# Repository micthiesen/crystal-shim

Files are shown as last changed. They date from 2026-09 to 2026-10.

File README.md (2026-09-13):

# Crystal Shim

A water-level interlock for an OASE CrystalSkim 350. An active sensor outside the
aquarium glass reports to an ESP32-C6; a separate mains board filters and switches
the skimmer. The controller and mains board share an enclosure with physical separation.

It runs on configurable 15-minute schedules when the water level permits, with
bounded HomeKit overrides. Every run ends automatically. See [behavior](docs/controls.md).
Pushover alerts report confirmed water-level transitions in either direction.
An ESP-hosted local webpage implements settings and schedules. The sensor
targets a freshwater tank with 5 mm glass. Its slim board adheres below the rim
with thin mounting film and a left-exiting pigtail.

**Build approach:** one complete design and fabrication cycle for all three
final-use boards. Complete design reviews before fabrication, then calibrate and
commission the assembled unit. No separate prototype phase is planned.

**Status:** the compact three-board designs are prepared for owner routing.
See [current state](docs/STATE.md) for current checks and accepted handoff receipts.
The C6 application includes sensing, relay/watchdog control, retained state,
private Matter provisioning, local settings and verified-TLS Pushover delivery.
The present hardware includes fixed 12 V power, three future pump drivers and a
second sensor port under the [refill attachment contract](docs/design/refill-expansion.md).
Future refill/conditioning behavior is deferred. Routing, fabrication release and
physical calibration/commissioning remain separate work.

Start with [the overview](docs/overview.md) and [current state](docs/STATE.md).
The [decision register](docs/decisions.md) tracks open inputs and release gates.

- [Design dossier](docs/README.md)
- [Firmware and simulator](firmware/README.md)
- [PCB tooling and three board areas](pcb/README.md)
- [Bill of materials](bom/README.md)
- [Commissioning matrix](testing/README.md)
- [Build sequence](docs/build.md)

Use the pinned toolchains described in the firmware and PCB READMEs. Then:

```sh
cd pcb
bun install --frozen-lockfile
cd ..
sh scripts/check.sh
python3 .agents/skills/sync/sync-status.py
```

Based on `../stillair`: Rust host core + CLI + separate ESP32-C6 app, Bun/tscircuit
authoring, and KiCad downstream production tooling. Relevant skills and tools have
a reciprocal sync map; Stillair's board designs and fan behavior are not imported.

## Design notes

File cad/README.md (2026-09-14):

# Mechanical artifacts

The [stencil fixtures](stencil-fixtures/README.md) provide printable PETG trays
for the three ordered PCBs, with STEP/STL/3MF exports, nominal shims, parametric
CadQuery source and digital fit checks. Physical fit remains untested.

The current [shared-enclosure plan and CAD screen](shared-enclosure/README.md)
uses Hammond 1590ZGRP243 for the stacked mains and controller boards. It retains
the manufacturer PDF and STEP archive, reproducible CadQuery script, actual
collision/distance results, negative controls and a reloaded STEP export.
See [mechanical requirements](../docs/mechanical.md) for mounting and cable limits.

`controller-fit/` and `mains-fit/` are historical nominal fit evidence for the
superseded 1554V2GY enclosure and earlier PCB sizes. Their machining, carrier,
portal and mating assumptions must not be applied to the current boards.

No enclosure production machining drawing is released.
The sensor uses thin adhesive film directly against the glass; no clip is required.
Its board and pigtail interface are specified in the mechanical requirements.

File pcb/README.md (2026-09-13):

# PCB workspace

All three product boards have accepted native schematic/placement handoffs with
prepared pours, routing widths and native DRC rules. Controller and mains share
150 × 110 mm outlines and aligned mounts; the adhesive sensor is 18 × 64 mm.
Expected unrouted connections are controller 166, mains 31 and sensor 21.
[STATE](../docs/STATE.md) records current per-board receipts and the six exact
sensor inner-shield padstack exceptions. Routing, final checks and fabrication
exports follow; physical commissioning remains separate.

Design the three boards as one final-use set for a single fabrication cycle.
Complete part, interface, enclosure and source/layout reviews before release.
There is no separate sensor prototype or planned board respin. Sensor calibration
and actual-load verification use the final boards after assembly; they do not
block the complete design's fabrication release. See [build order](../docs/build.md).

| Board | Role | Requirements |
| --- | --- | --- |
| [sensor](sensor/README.md) | External active capacitance sensor stick | [Sensor](../docs/sensor.md) |
| [controller](controller/README.md) | Low-voltage ESP, relay and future pump drivers, two sensor ports and USB | [Electrical](../docs/electrical.md) |
| [mains](mains/README.md) | Protected power input, isolated supply and pump switching | [Electrical](../docs/electrical.md) |

Use the local [PCB skill](../.agents/skills/pcb/SKILL.md) for product authoring, then
[Konnect](../.agents/skills/konnect/SKILL.md) and
[fabrication](../.agents/skills/kicad-manufacture/SKILL.md) for downstream work.
Tscircuit owns schematic, specifications, and placement; KiCad owns routing
and declared manufacturing additions. Do not create a fabrication profile before
the corresponding board and order requirements exist.

## Tooling validation

Versions and Oxc conventions come from Stillair. TypeScript is pinned to 5.9.3.
The root `.bun-version` and `.node-version` record the verified CLI runtimes;
`tsci` uses Node even though Bun manages dependencies and scripts.
From this directory:

```bash
bun install --frozen-lockfile
bun run check
bun run typecheck
bun run check:smoke
bun run test
bun run test:handoff
```

`fixtures/tooling-smoke.circuit.tsx` is a TOOLING-only, arbitrary RC circuit. Its
parts, values, dimensions and nets are unrelated to Crystal Shim. It checks that
the installed TSX compiler, placement, netlist and multi-file KiCad schematic
export work. Fixture outputs go under ignored `dist/`; they are unrelated to the
adopted controller. `bun run dev:smoke` opens the local fixture viewer when needed.

The Python tests exercise generic handoff protections using self-contained
synthetic fixtures. Passing this gate proves tooling behavior, not electrical
safety, sensor performance, real KiCad handoff parity, ERC/DRC, or fabrication
readiness. Native handoff requires the local KiCad macOS bundle and separate
evidence for each actual board. See [tools](tools/README.md).

The pinned build currently emits missing schematic reference-designator styling
warnings for the fixture's built-in R1/C1 symbols. The exported KiCad sheet is
tested to contain both reference fields. These warnings remain visible; future
product schematics require the separate render and parity review gates.

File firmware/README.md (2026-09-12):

# Firmware

Rust, bare-metal ESP32-C6, following `../stillair`: `core/` contains the `no_std`
control contract, `drivers/` contains async device drivers, `cli/` runs the control
model on the host, `matter/` contains the actual SDK command and KV adapters,
`settings/` supplies the local HTTP service/UI, `pushover/` owns bounded RAM
events and HTTP delivery policy, and `roughtime/` verifies signed time replies offline. `app/` is a separate workspace
targeting `riscv32imac-unknown-none-elf`. Stable Rust is declared in
`rust-toolchain.toml`; setup was verified with Rust 1.97.1. Commit each workspace's lockfile.

The ESP image is **uncommissioned**. It binds the controller capture pin map,
acquires FDC1004 frames on a separate interrupt executor, runs a 20 ms relay-output
task, services a 1,500 ms system-reset watchdog only after that task completes, and
streams bounded USB diagnostics. Boot validates saved settings/calibration and repairs
retained safety state through a relay-off flash gate. Missing or invalid settings keep
the output off. The runtime coordinator evaluates schedules, persists configuration
and suppression, and accepts bounded physical USB administration. The Matter
command and shared KV adapters, Wi-Fi/BLE commissioning and private credential
provisioning are implemented. The private switch profile follows D-22; Apple Home
pairing and behavior have not been exercised. The authenticated
[settings service](../docs/design/settings.md) includes schedule, threshold and
response timing controls. The [Pushover worker](../docs/design/pushover.md) is
linked through the same network; physical calibration workflow remains work. The external coil
pull-down must establish off before application entry and during reset; a build
cannot verify that physical behavior.

The separate [FDC1004 driver](drivers/README.md) implements reset, identity/config
checks and complete sequential out-of-phase measurement frames, with host tests.
It is bound to the ESP's 100 kHz bus with finite transactions and power recovery.
The [calibration stage](../docs/design/calibration.md) applies measured tank data
without fabricated default thresholds. The [integration design](../docs/design/firmware-integration.md)
distinguishes implemented executor and storage adapters from remaining network
integration. The [runtime transaction contract](../docs/design/runtime-transactions.md)
defines configuration saves, command acknowledgements and the USB protocol.
The [Matter adapter contract](../docs/design/matter-integration.md) defines producer
ownership, cancellation, applied replies and the single shared SDK storage owner.
The [configuration](../docs/design/configuration.md),
[timezone](../docs/design/timezone.md) and [flash-storage](../docs/design/flash-storage.md)
records describe the bounded models and current evidence.

The app uses the same compatible esp-hal revision as Stillair,
`10e48dd74837bae4be663a7d1825d12875363727`, for HAL, panic/log output, bootloader,
and generated metadata. Its lockfile was seeded from Stillair's to retain the
same transitive versions. HomeKit through Stillair-style Matter over Wi-Fi is
selected; radio dependencies and the shared network adapter are linked.
Keep the esp-* dependency family on one compatible revision.

The [offline signed-time verifier](../docs/design/unattended-time.md) is a host
workspace member with a checked C6 `no_std` library build. It is not linked into
the app or accepted as UTC. Its public captures and synthetic test identity are
offline fixtures. Conservative interval scheduling is implemented and reviewed.
Interval TLS operation leases are implemented. Signed-source agreement, drift
policy and unattended runtime acquisition remain work.

## Control contract

Stop-low / automatic restart-after-refill is confirmed. `Supervisor` is the public
control entry point; the lower-level interlock is crate-private and cannot serve
as an unscheduled hardware entry point. The core uses injected monotonic milliseconds and
integer calibrated levels in `0..1000` thousandths of the selected sensing range.
These are calibrated fractions, not millimetres. The integer calibration stage
converts measured capacitance response into this domain.
No real stop/restart thresholds or maximum sample age are supplied by default.

- Boot starts off. Automatic restart requires valid readings at or above the configured
  restart threshold, ten seconds of stable recovery, and thirty seconds off.
- During automatic operation, a level at or below the lower stop threshold must persist for
  one second before off. Readings above that threshold reset low confirmation.
- Disconnected, uncalibrated, out-of-range, bus-failed, stale, or future-dated
  readings cause immediate off. A backwards clock or a control-loop gap longer
  than the configured sample-age deadline also forces off.
- Recovery resets on faults and readings below the restart threshold. Cached
  readings retain their acquisition timestamp and cannot establish a recovery
  interval by themselves. The caller must tick periodically even without data.
- A manual override can bypass low-level and recovery gates for a valid, fresh
  sensor. It cannot bypass faults, maintenance, hardware-forced-off, or minimum
  off time. Faults, maintenance, and hardware-forced-off cancel an override rather
  than queueing it for later. A scheduled request can recover inside its original
  remaining window.
- Maintenance stays off until an explicit exit command. The runtime persists
  maintenance and window suppression through the gated storage owner, and exits
  maintenance only after its clear record is durable. Exit then requires fresh
  stable recovery. Final-board power-cut behavior still requires measurement.
- Network state is absent from the control contract, so future network tasks
  must not be able to prevent local sampling/control ticks.

The 1 s / 10 s / 30 s values are proposed tuning values from the design brief,
not validated OASE requirements. The maximum sample age also serves as the
allowed control-loop gap in this baseline. Set it from the selected acquisition
cadence and measured failure response. `RelayCommand` describes the requested
coil state; it provides no contact feedback or protection from welded contacts.

## Scheduled operation and HomeKit

`Inputs` carries a reading, optional `ScheduledWindow`, `SwitchCommand`,
maintenance command, and `HardwarePermit`. The runtime calendar adapter supplies
only active windows with a stable, strictly increasing `WindowId` and the
original absolute monotonic `ends_at`. It must preserve identities across
repeated ticks and schedule edits. `schedule.rs` implements bounded daily entries,
injected timezone resolution and stable occurrence IDs. `retained.rs` implements
the versioned safety record and boot recovery policy. The core timezone resolver
accepts explicit POSIX rules. The app loads saved settings, repairs retained state
at boot and stores eligibility before exposing a scheduled window. USB can supply
an explicit UTC observation; it ages automatically and expires after one hour.
The [trusted UTC path](../docs/design/trusted-utc.md) can also read an
administrator-configured Matter CASE source. A usable Home hub source has not
been demonstrated; unattended time availability remains open. No hours are guessed.
The intended starting schedule is fifteen minutes a few times per day.

Every run has an absolute deadline. The initial configurable maximum duration is
`900000` ms; the scheduler's window end may make an automatic run shorter. Low
water, recovery waits, and interruptions consume the available window. Recovery
never grants time beyond that end. A replacement or overlapping window cannot
extend an active run's original deadline. At expiry the supervisor forces off;
a later distinct window remains eligible after minimum-off and fresh recovery.

HomeKit exposes an advisory switch plus a temporary override:

- Off cancels any override, immediately requests off, and suppresses the remainder
  of the current scheduled window. A later distinct window is eligible again.
- On outside a window, or when automatic operation is stopped at valid LOW,
  requests an override for the configured maximum duration. Its deadline starts
  at the **request timestamp**. Minimum-off waiting consumes part of that allowance.
- Repeated On while an override is pending/running retains its original deadline.
  On during an energized automatic run may select override mode but retains that
  run's original deadline. It does not grant a fresh fifteen minutes.
- An On arriving on the expiry tick cannot renew the active run. A subsequent
  explicit On is a new request and still observes minimum off. Off followed by
  a new explicit On is also allowed.
- An override expires to off. It does not fall back into automatic operation in
  the current window. Neither HomeKit nor a schedule can command indefinite on.

All thresholds and timers are explicit configuration. The CLI supports them at
startup; `Supervisor::reconfigure` clamps an active deadline when duration decreases
and never extends it when duration increases. The runtime's configuration-save
transaction deliberately enters maintenance, preserves deadline history and
requires an explicit durable exit. The implemented [settings webpage](../docs/design/settings.md)
shows this consequence and keeps maintenance exit separate. Use the private
[first-configuration workflow](../docs/design/first-configuration.md) before Matter
commissioning. No final Matter node has been physically commissioned yet.
The generated async Matter handler reports the observed relay command and waits
for control-applied replies. Source-owned tokens prevent stale replies or another
producer from consuming them. Toggle resolves inside control. The linked radio
adapter preserves this boundary and runs the attribute notification handler;
final hardware behavior remains unverified.

## Water notifications

`SupervisorStatus.water_transition` emits one confirmed HIGH-to-LOW or LOW-to-HIGH
edge for the normal-priority Pushover adapter. Detection is independent of
relay command, schedule, manual override, and hardware permission. It uses the
same stop/restart thresholds and low/recovery confirmation delays. Initial valid
classification establishes a silent baseline. Intermediate-band readings and
invalid/stale data reset pending confirmation without inventing a water change.
Cached samples cannot prove a transition. `status()` does not replay an event.

Changing interlock configuration resets pending level confirmation and the notification baseline so calibration
or threshold edits do not masquerade as water movement. The [worker](../docs/design/pushover.md)
captures the fresh step after GPIO output, retains at most eight RAM events for
15 minutes, and uses one original 20-second TLS/HTTP deadline per attempt. It
checks the accepted clock authority, network and configuration token around
every I/O poll. There are at most three attempts; uncertain failures may duplicate
a message. Accepted settings replacement cancels old work before flash; failure
keeps delivery paused until a later save commits. HTTP 4xx or a complete API rejection suspends the credential generation
until it is changed or explicitly disabled and restored. Reboot clears queued
work and suspension. No live notification was sent.

## Verify

Run from the repository root. These are the same checks as
`.github/workflows/firmware.yml`:

```bash
sh scripts/check-tls.sh
cd firmware
cargo fmt --check
cargo clippy --locked --all-targets -- -D warnings
cargo test --locked
cd app
cargo fmt --check
sh ../../scripts/with-esp-toolchain.sh cargo clippy --locked --all-targets -- -D warnings
sh ../../scripts/with-esp-toolchain.sh cargo build --locked --release
cd ../..
python3 scripts/check_matter_features.py
```

Use `cargo fmt` in the appropriate workspace to apply formatting. The host tests
exercise meaningful control and parser behavior; the target build only proves
that the local-runtime image links. The separate TLS construction probe and host endpoint
checks are recorded in the provider document. Clang with a RISC-V backend is
required for its portable C dependency; on macOS the wrapper finds installed
Homebrew LLVM. No hardware or mains testing is implied.

The TLS policy harness compiles the production provider source directly and runs
offline certificate and clock tests on Linux. `scripts/check-tls.sh` uses native
Linux or the default OrbStack Linux machine on macOS. That environment needs Rust,
Clang, libclang and CMake. The script also checks production/test dependency and
crypto-feature parity; it does not silently skip TLS tests on an unsupported host.

## Host simulator

From `firmware/`, run `cargo run --locked -p crystal-shim-cli -- --help`. The CLI
accepts stop threshold, restart threshold, and maximum sample age, optionally
followed by low-confirmation, recovery, minimum-off, and maximum-run durations in
milliseconds. Omitted durations use the initial 1 s / 10 s / 30 s / 15 min seeds.
It reads one persistent simulation from stdin. Each event carries the injected
timestamp. It prints CSV control state, relay command, demand, deadline, water
classification and transitions, and exits
nonzero for malformed commands. Fault events are successful simulation inputs.

This short example uses **synthetic values**, not calibration recommendations:

```bash
printf '0 level 600\n0 window 1 900000\n100 disconnected\n200 maintenance-on\n300 level 600\n400 maintenance-off\n' |
  cargo run --locked -p crystal-shim-cli -- 200 400 500
```

Supported lines are `<ms> level <0..1000>`, `<ms> tick`, `<ms> disconnected`,
`<ms> uncalibrated`, `<ms> out-of-range`, `<ms> bus-fault`,
`<ms> maintenance-on`, `<ms> maintenance-off`, `<ms> window <id> <absolute-end-ms>`,
`<ms> no-window`, `<ms> on`, `<ms> off`, `<ms> hardware-off`, and
`<ms> hardware-on`. Blank lines and `#` comments
are ignored. `tick` reuses the last reading without renewing its timestamp.
Supply successful acquisitions frequently enough to meet the configured age
deadline. A single leap forward in time cannot simulate uninterrupted sampling.

Bind hardware drivers to reviewed GPIO/net assignments from the complete board
design. During commissioning of the final assembled boards, validate electrode
calibration on the confirmed glass/range, measured thresholds, maximum sample age
and cadence, watchdog behavior, maintenance/window-suppression persistence,
calendar scheduling, Matter/Pushover adapters, and diagnostic storage/transport
for raw capacitances, interpreted level, validity, relay command and reset reason.
Physical calibration follows fabrication; it does not block implementing the
hardware bindings.

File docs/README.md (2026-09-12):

# Design dossier

The 2026-09-11 setup request is the initial design brief. These documents retain
its architecture, provisional choices, caveats, and acceptance goals. Verified
manufacturer facts are linked separately from proposed design decisions.

The owner selected a one-shot build: develop and review the complete three-board
design, fabricate one final-use set, then calibrate and commission it. The
[build sequence](build.md) separates design evidence required before fabrication
from measurements performed on the final assembly.

| Document | Owns |
| --- | --- |
| [Overview](overview.md) | Purpose, scope, board split, functional diagram |
| [Electrical](electrical.md) | Power, mains switching, noise suppression, interfaces |
| [Sensor](sensor.md) | Electrodes, daughterboard, calibration, glass validation |
| [Controls](controls.md) | Local firmware contract, diagnostics, provisional timing |
| [Mechanical](mechanical.md) | Enclosure separation, installation, assembly |
| [Decisions](decisions.md) | Baseline, open inputs, release gates |
| [Build](build.md) | Development and commissioning order |
| [Sources](sources.md) | Manufacturer references and Stillair evidence |
| [Detailed design](design/README.md) | Parts, geometry, interfaces, calculations and firmware integration under review |
| [Active goal](goal.md) | Full implementation, adversarial review and delivery scope |
| [STATE](STATE.md) | Current work and next step, with pointers to durable facts |

`Proposed` means a starting choice; `open` means unspecified; `verified` requires
linked evidence. A component rating does not establish whole-product compliance.
Update the owning document, BOM, and test matrix together when a choice is resolved.
`Capture candidate` identifies an exact proposed part with source evidence; it
does not mean the layout has passed release review or that procurement is ready.

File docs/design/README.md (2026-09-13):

# Detailed design basis

These documents turn the requirements into concrete engineering selections for
schematic and firmware implementation. They are candidates under review, not fabrication
release or commissioning evidence. Their explicit open items remain work to finish.

- [Sensor](sensor-design-basis.md): TI OoP topology, glass/rim geometry, references,
  local regulation, I2C, adhesive interface and retained visual reference.
- [Sensor-cable protection](sensor-cable-protection.md): exact ESD selections,
  bus loading and final-system immunity limits.
- [Sensor power refinement](sensor-power-refinement.md): RC protection, PGFB diode,
  voltage/load/capacitance budgets and finite backfeed calculations.
- [Controller](controller-design-basis.md): module pins, power and service inputs,
  USB attach gating, relay driver, power-good interlock and harnesses.
- [Controller service pads](controller-test-points.md): exposed supply, bus, relay
  and UART points, probe access, mask and no-paste export rules.
- [Mains and enclosure](mains-design-basis.md): PSU, relay, filter, fuse/MOV/RC,
  mains harness, PE, spacing and enclosure allocation.
- [Secondary power protection](power-protection-review.md): selected 2 A supply,
  reverse-blocking eFuse networks, static margins and remaining transient review.
- [Firmware integration](firmware-integration.md): schedule/retained state,
  executor ownership, Matter, HTTP, Pushover, storage, USB and resource gates.
- [Calibration](calibration.md): measured TI response normalization, integer arithmetic,
  raw envelopes, frame ordering and validity checks.
- [Configuration](configuration.md): validated settings and canonical bounded storage format.
- [First configuration](first-configuration.md): private initial record creation,
  offline validation and one-shot USB delivery before Matter commissioning.
- [Local settings](settings.md): actual HTTP service, browser UI and durable command admission.
- [TLS restriction](tls-restriction.md): borrowed rejection-only certificate callback,
  interval operation lease and vendor provenance.
- [Pushover delivery](pushover.md): fresh water events, bounded RAM queue, verified
  HTTP worker, cancellation and failure diagnostics.
- [Controller grid](controller-grid.md): initial coordinate conversion and verified native-save connectivity.
- [Timezone](timezone.md): explicit POSIX rules, DST folds/gaps and calendar limits.
- [Flash storage](flash-storage.md): output-off ownership, bounded flash chunks and boot recovery.
- [Runtime transactions](runtime-transactions.md): durable settings, schedule eligibility,
  immediate Off, sensor revisions and bounded USB administration.
- [Matter adapter](matter-integration.md): generated command handling, producer ownership,
  applied reporting, shared gated KV and the remaining radio/profile integration.
- [Verified TLS](tls-provider.md): fixed Pushover trust policy, C6 build,
  live endpoint checks, measured linked size and remaining runtime evidence.
- [Footprint audit](footprint-audit.md): installed-library candidates, manufacturer
  comparisons and exact patterns still required before capture release.
- [Manufacturing output profile](manufacturing-output.md): three-board assembly split, order construction, export path and final checks.
- [Review record](review-log.md): findings, corrections, rejected claims and
  scopes that still require review.

The [active project goal](../goal.md) covers implementation, repeated adversarial
review, manufacturing output and final-unit commissioning support. No board is
released by a document's use of an exact part number or dimension.

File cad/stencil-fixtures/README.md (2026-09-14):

# PCB stencil fixtures

Three square PETG trays for the ordered bare PCBs, with a flat stencil/tape
surface, oversized pocket, three locating pads and three flexible edge tabs.
Source uses **CadQuery 2.8 + uv**, the same approach as `../cat-water-cover`.
All dimensions are millimetres. STEP, STL and geometry-only 3MF exports are
already oriented flat on the bed, pocket upward, at Z=0.

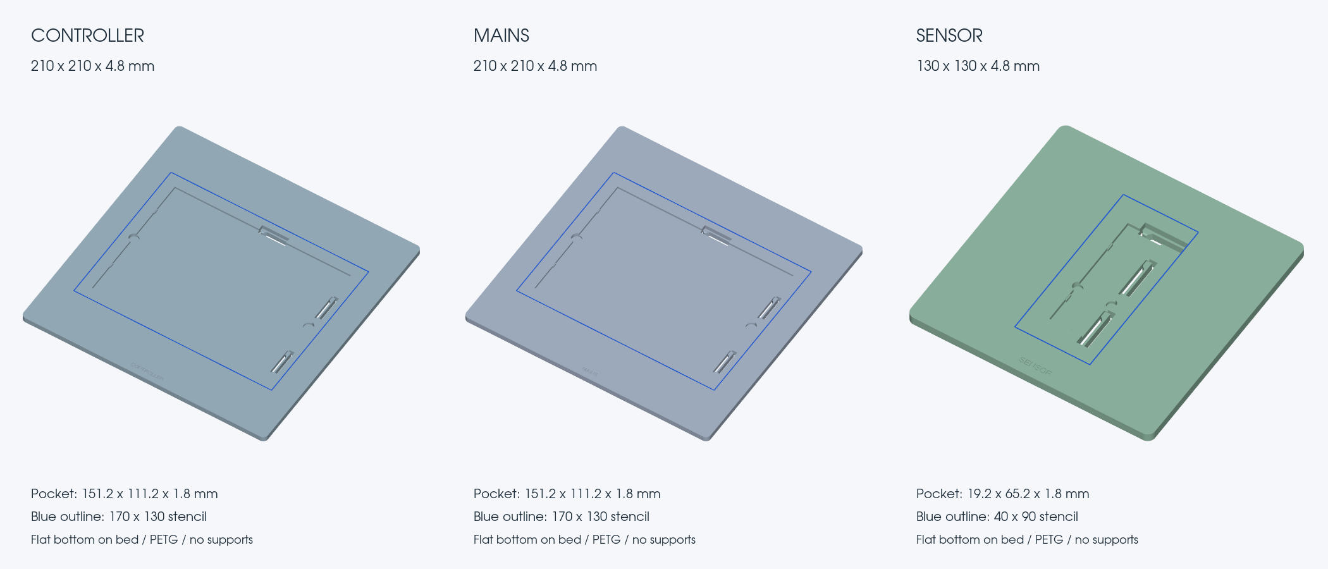
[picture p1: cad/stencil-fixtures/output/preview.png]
Rendered STEP trays; blue outlines show the custom stencil sizes


## Print files

| PCB | Tray STEP | Outer size | Pocket, before locating features | Ordered custom stencil |
| --- | --- | --- | --- | --- |
| Controller | [controller-tray.step](output/controller-tray.step) | 210 × 210 × 4.8 | 151.2 × 111.2 × 1.8 | 170 × 130 |
| Mains | [mains-tray.step](output/mains-tray.step) | 210 × 210 × 4.8 | 151.2 × 111.2 × 1.8 | 170 × 130 |
| Sensor | [sensor-tray.step](output/sensor-tray.step) | 130 × 130 × 4.8 | 19.2 × 65.2 × 1.8 | 40 × 90 |

Each has matching `.stl` and `.3mf` files in `output/`. The two large trays have
the same fit geometry and different recessed names. One large tray can serve
both PCBs if doing them in sequence. There are also three separately exported
`*-shim-0.2mm.step`, `.stl` and `.3mf` sheets for nominal height adjustment.
The shims are optional print files: measured thin sheet material works too.

The centred stencil has 20 mm minimum border beyond its edges: 20/40 mm in
X/Y for the large trays, 45/20 mm for the sensor. The tray does not locate or
recess the stencil. Align its apertures visually to the pads and tape onto the
flat border. The blue lines are preview annotations, not printed grooves.
The purchase listing's 380 × 280 mm stock size is recorded separately from its
custom cut sizes in the [order record](../../bom/purchases/W2026091502305469/README.md).
Actual aperture centring within each supplied sheet is unmeasured.

## Material and slicer settings

**Use ordinary PETG**, with a 0.4 mm nozzle. The broad tray should stay firm
under a squeegee; flexibility is concentrated in the thin tabs. PETG has useful
toughness and some flexibility ([Prusa material guide](https://help.prusa3d.com/article/petg_2059)).
TPU would make the entire support more compliant and is not the selected
material. PLA may work, but the spring design has not been checked with PLA.

- Print one tray flat, pocket up, at **100% scale**. No supports or raft.
- Use **0.20 mm layers**, including the first layer, **4 walls**, **5 top and
  5 bottom layers**, and about **25% gyroid infill**. Select your filament's
  normal PETG temperature/flow profile.
- The 1.2 mm beams are three nominal nozzle widths. Inspect the sliced preview
  to ensure continuous walls in each beam and clear slots. Keep automatic
  supports off and prevent brims from filling the internal spring slots.
- Use a clean, flat build plate. Use an external brim only if your PETG profile
  needs it; remove it fully. Keep the tray on a hard, flat bench during pasting.
- Remove strings and any raised top-surface defects. Do not round the seating
  plane or datum pads. Check the tray does not rock and the pocket floor is flat.
- Print a nominal shim separately as **one 0.20 mm layer**, 100% solid, no brim
  or ironing. Its actual thickness still needs checking; a calibrated sheet is
  preferable if first-layer variation makes the printed shim uneven.

The 210 mm tray fits the smaller 235.5 × 256 mm nozzle envelope used by the
cat-water-cover project. No printer preset or sliced toolpath is embedded in
these exports. This is an ambient-temperature paste fixture; lift the PCB out
before hot-bed/reflow work.

## Flush height and use

All three PCB orders specify **1.6 mm nominal thickness**. JLCPCB publishes
1.44–1.76 mm for this thickness ([capabilities](https://jlcpcb.com/capabilities/pcb-capabilities)).
The **1.8 mm pocket** allows a shim under even a thicker board. A nominal
1.6 mm board plus a **0.2 mm shim** brings its top to the 4.8 mm tray surface.
The stencil foil sits on top of both surfaces; its thickness is not added to
the pocket depth.

1. Clean the bare PCB and tray. Before any paste, measure the PCB thickness
   and the actual printed pocket depth.
2. Select a broad, flat shim: **shim thickness = pocket depth − PCB thickness**.
   For the nominal model, the published board tolerance needs 0.04–0.36 mm.
   Use measured polyester/Kapton sheet or evenly stacked thin paper if the
   supplied 0.2 mm print is not right. Cover the support floor broadly; avoid
   small stacks at isolated points that let the board bend under the squeegee.
3. Set the shim on the floor, clear of the spring slots. Lower the PCB against
   the left and bottom datum pads. Gently pull the right/top tabs outward as
   needed; their bevels assist insertion. They press on the edges, with no lip
   over the board. Do not force a board through a tight or fused slot.
4. Lay a straightedge across the tray and PCB in several directions. Adjust
   until they are coplanar, without a visible step or a gap beneath the stencil
   at the paste openings. Target within approximately 0.05 mm; the printed shim
   alone does not establish this. If the bare PCB stands proud without any shim,
   deepen/regenerate the pocket rather than force the stencil flat.
5. Visually align the stencil and tape a hinge along one edge. Tape the opposite
   edge after checking alignment. Place tape outside the PCB/paste field and
   away from the moving tabs. Confirm the PCB cannot shift in a dry pass.
6. Squeegee toward the fixed left/bottom pads so the stroke pushes the PCB into
   its stops. Lift the stencil on the tape hinge, then lift the PCB through
   the two small edge wells with a plastic pick while easing the tabs back.
   The wells expose an underside edge without making large holes under the PCB.

Paste all three boards **before through-hole parts or the sensor pigtail**.
These fixtures are for the single top-side bare-board pass in the
[assembly guide](../../docs/assembly/README.md).

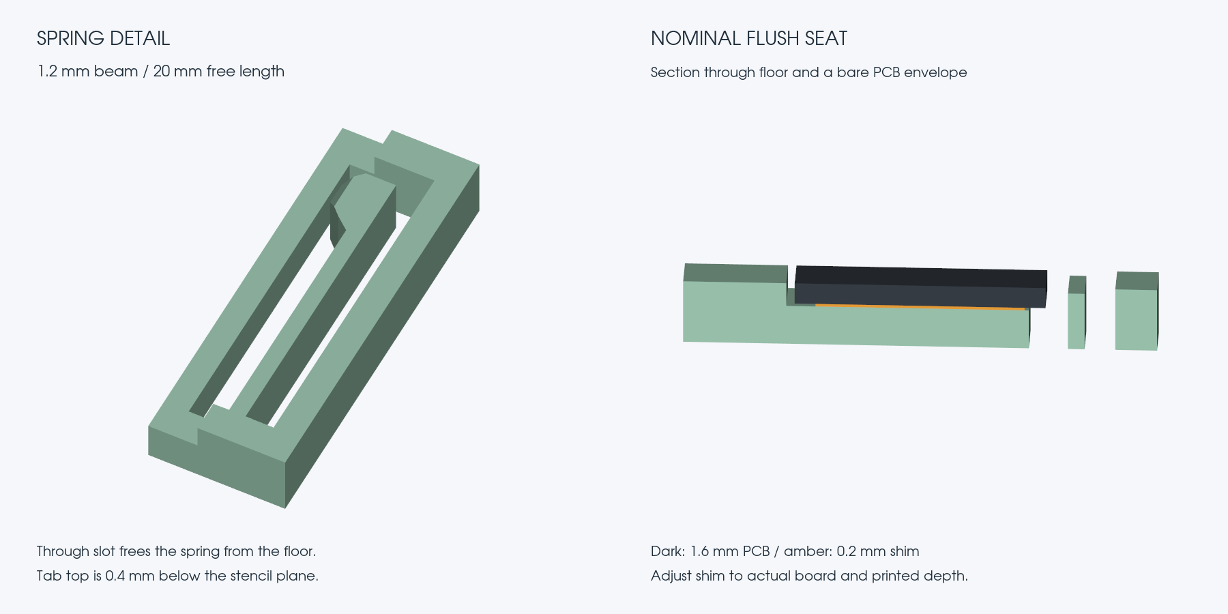
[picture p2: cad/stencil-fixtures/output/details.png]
Spring detail and section through the nominal flush PCB and shim


## Fit features

- Pocket clearance is 0.6 mm per side, with square inside corners to accommodate
  the released sharp rectangular board outlines and unspecified sensor deburring.
- Two left pads and one bottom pad establish position. Two right springs and
  one top spring press the board against those pads.
- Each spring has a 1.2 mm beam, approximately 20 mm free length, 0.6 mm nominal
  preload and 1.2 mm checked lateral free travel. The ordered ±0.2 mm outline
  tolerance requires 0.4–0.8 mm nominal deflection. Remaining travel provides
  adjustment margin, not a guarantee of printer accuracy or holding force.
- Slots extend through the tray, so the floor does not lock the springs in
  place. Everything grows upward from the bed without a suspended underside.
- Tabs and datum pads finish 0.4 mm below the stencil-support plane. Text is
  recessed. There are no locating pins through stencil holes or PCB mounts.
- The 3 mm floor and broad shim support the bare PCB during squeegee pressure.

## Rebuild and review

```sh
cd cad/stencil-fixtures
uv sync --locked
uv run python build.py
uv run python validate.py
uv run python render.py
```

`build.py` owns all dimensions. If revising `DEPTH` for a measured board, retain
layer-compatible heights and review `SHIM`, the nominal shim filenames, the
validator's thickness/shim limits and the section preview together. Rerun all
three commands after a geometry change.
`output/parameters.json` binds dimensions to the order and released outline
Gerber hashes. `output/validation.json` binds the exported print geometry to its
source and dependency lock. [review.json](output/review.json) records this
release's independent and visual review; changed source/exports invalidate its
hashes and need another review.

The validator reloads STEP files, checks single valid solids and watertight
STL/3MF meshes, compares nominal source/export geometry, checks all 27 combinations
of board length/width/thickness per tray, checks spring clearance and intentional
preload, rejects an oversize-board negative control, checks shim clearance and
removal, and checks that consecutive 0.2 mm layer sections need no overhang
support. Spring displacement checks translate the free beam envelope; they are
not finite-element analysis. The simple maximum beam-strain estimate is 0.54%,
without a material strength or fatigue claim.

The previews render the exported STEP solids. PCB blanks and blue stencil
outlines are labelled nominal envelopes. Physical fit, retention force, print
flatness and paste results remain untested until the boards arrive. The
supplier-selected stencil foil thickness also remains unconfirmed; the earlier
0.10 mm paste review is a design basis, not evidence of the delivered foil.

**2026-09-14 review:** all six STEP/STL/3MF parts passed, with 81 PCB tolerance
cases across the three trays. Independent review found and closed a sensor
access-well/spring conflict; final renders were inspected. `sh scripts/check.sh`
passed, with its 43 conditional native integration checks skipped by the normal
harness. No native PCB file changed, and no electrical review or physical test
is claimed by this fixture work.

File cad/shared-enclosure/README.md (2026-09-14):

# Shared enclosure fit

The retained **Hammond 1590ZGRP243** accommodates the matching **150 × 110 mm**
boards as a stack, controller above mains, with **45 mm clear board-face spacing**.
The separate mains filter remains beside the stack. This screen uses actual
manufacturer enclosure solids and declared rectangular assembly/access reserves;
it does not establish exact component, cable, insulation or thermal acceptance.

- [Fit results](fit-results.json): dimensions, clearances, sensitivity and negative controls.
- [CAD screen](fit-screen.step): enclosure and current stacked reserve solids.
- [Manufacturer drawing](source/1590ZGRP243.pdf) and original STEP ZIP are retained.
- [Reproduction script](check_fit.py): requires CadQuery; run
  `python cad/shared-enclosure/check_fit.py`.
- [Old side-by-side plan](fit-plan.svg): historical, superseded by this stack.

Both board outlines occupy X100..250, Y65..175 mm in enclosure-floor coordinates.
Mains PCB bottom/top are Z15/16.6; controller bottom/top are Z61.6/63.2.
Four aligned mounting columns have centres **(107,72), (243,72), (107,168),
(243,168)**. Use insulating M3 hardware within the 8 mm maximum reserved diameter.
The selected support construction below fixes spacer, washer and carrier geometry;
board-load and fastening performance remain physical checks.

An **intact 158 × 118 × 2 mm insulating separator** occupies X96..254,
Y61..179, Z50.1..52.1. Its lower face is 3 mm above the allocated 30.5 mm supply
height; it leaves 6.5 mm to the upper assembly's underside reserve at Z58.6.
The support construction below selects FR-4 and edge retention without separator
penetrations. Wire routing and as-built electrical insulation still need inspection.
No RF notch is selected.

Allow **35 mm outward mating/wiring depth** at each used edge. Lower primary
fixed terminals exit left and south; lower isolated headers exit right. Upper sensor
headers exit north, service connectors south and pump outputs right. The north
reserve stays left of the antenna. These are space allocations, not measured
housing withdrawal distances, cable bend radii or exact crimp models. Mains
J1–J4 now use 21.5 mm-high Phoenix Contact 1868076 terminals, within the existing
30.5 mm lower assembly height reserve. Their top screws require removal of the
controller and separator with mains disconnected. The gross reserve geometry
is unchanged; the historical fit receipt is not an exact terminal assembly model.

The filter/wiring reserve is rotated to **75 × 130 × 40 mm**, at X292..367,
Y40..170, Z10..50. Its nominal enclosure clearance is **5.40 mm**; expanding the
reserve by 1 mm and lowering the lid/hardware 1 mm leaves **4.00 mm**. Keep LINE
and LOAD wiring separate. This reserve contains the retained external filter and
its cable allowance, not an added component or a final mounting drawing.

The module's actual antenna envelope remains beyond the upper board's north
edge. Its minimum distance to the lower assembly reserve is **16.1 mm**. The
screen checks at least 15 mm to the enclosure, lower components, filter and
external harness reserves. The intact dielectric separator is tracked separately;
its influence on RF performance remains unmeasured. The board's local copper
exclusion and module support rules remain authoritative.

The optional manufacturer steel inner panel is excluded. Base, lid, screws and
gasket remain in every enclosure test. All nominal reserve volumes and the 1 mm
expanded reserves clear the enclosure, including a lid lowered 1 mm to account
for the STEP/drawing height discrepancy. Independent reserves do not intersect;
intentional mating interfaces may touch. Three negative controls detect wall,
lid and lowered-separator collisions. The exported STEP reloads as **19 valid
solids**. No route, fabrication, machining or assembled ingress rating follows
from this gross-fit result.

## Selected insulating support assembly

[Support construction](../../docs/design/evidence/pre-fab-2026-09-14/mechanical-closure.md)
now specifies a stock FR-4 carrier, two upper rails, four external nylon rods and
corner clamps that preserve the hole-free separator. The PCB elevations and hole
pattern above remain unchanged. [Support CAD](support-fit.step) and
[results](support-fit.json) are reproduced with `python check_supports.py` from
this directory, using the same CadQuery environment as the original fit screen.

The precise manufacturer-solid check locates the inner base surface at **Z1.8**
and outer base surface at **Z−4.0** at all six chosen base fastenings. Earlier text
called the retained Z0 datum the floor; it is a reference datum, not that local
surface. Carrier feet therefore have **3.2 mm** effective height to carrier Z5.
The new geometry checks actual base material, support/harness interference and
negative controls. Exact fastener engagement, physical loads, sealing, PE continuity
and the dielectric supports' RF effects remain assembly/commissioning checks.

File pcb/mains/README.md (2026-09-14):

# Mains board

The 22-part shared-power source and 150 × 110 mm placement allocation live in
[design](design/README.md). The IRM-45-12 supplies a separately fused 12 V motor
feed and AP63205-regulated 5 V controller/relay rail. The original skimmer filter
and relay behavior remain. F3 is the board-mounted T1A filter branch fuse; F2 is
the 3 A motor-feed fuse. F1 inlet fuse, manufactured filter and continuous PE
wiring remain offboard.

See the [design basis](../../docs/design/mains-design-basis.md),
[placement](../../docs/design/mains-placement.md), and
[native handoff](../../docs/design/mains-native-handoff.md). The [native project](kicad/README.md) has the accepted stacked placement,
right-angle connectors, filled isolated pours and installed routing rules.
Routing is accepted with zero unconnected items and clean strict ERC/parity/DRC.
See [routing acceptance](../../docs/design/evidence/mains-routing-acceptance/README.md).
Combined three-board pre-fabrication review remains pending.

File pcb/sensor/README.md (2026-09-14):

# Tank sensor daughterboard

The [authoritative source](design/README.md) captures and places the final-use
FDC1004 board for 5 mm freshwater aquarium glass and a 50 mm physical span below
the rim. Optional live dry RE is omitted in favour of stored dry baselines.
A future reservoir sensor may reuse the electrical interface, but its electrode
geometry is outside the present feature scope.

The accepted [native project](kicad/README.md) is 18 × 64 mm with four layers,
horizontal glass-side electrodes, inner driven shields and a left-exiting soldered
pigtail. Owner routing is complete with zero unconnected items; the exact routing is
accepted separately from the final three-board pre-fabrication review. See [STATE](../../docs/STATE.md) for validation and the
exact intentional inner-shield padstack exceptions.

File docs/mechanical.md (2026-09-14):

# Enclosure, mounting and assembly

## Shared controller and mains stack

Use matching **150 × 110 mm** boards, with the four-layer controller above the
two-layer mains/power board. Both are nominal 1.6 mm FR4 with components upward.
This is the accepted compact layout: the mains board shrinks from 180 mm wide,
while the controller grows from 110 mm to share its outline. The stacked bare
PCB footprint is 16,500 mm², approximately 48% below the former combined board
area. Connectors, cables, antenna, external filter and enclosure add space.

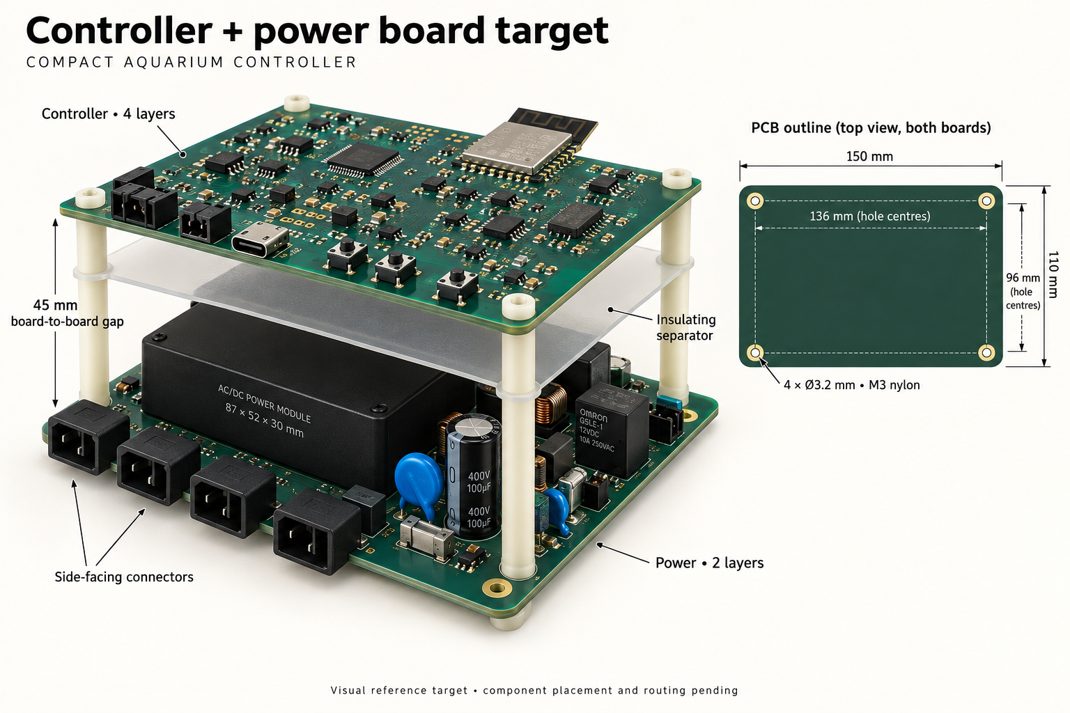
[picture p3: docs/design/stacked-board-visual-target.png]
Accepted stacked-board appearance


The generated visual reference is illustrative. Component appearances, connector
counts and relay markings do not change the BOM. The selected 5 V relay and
power architecture remain authoritative; no extra rendered capacitors or parts
are added. Source placement and native checks govern exact geometry.

| Mounting feature | Requirement |
| --- | --- |
| Holes on both boards | Four aligned 3.2 mm NPTH holes |
| Centres from upper-left, X right/Y down | (7,7), (143,7), (7,103), (143,103) mm |
| Source-centred coordinates | X=±68 mm, Y=±48 mm |
| Centre spacing | 136 × 96 mm |
| Hardware | M3 insulating screws, washers and standoffs |
| Hardware reservation | At least 4 mm radius per hole, no component/copper occupancy |
| Clear separation | 45 mm from lower PCB top face to upper PCB underside |

Match effective spacer length after washers and separator supports. Reserve
approximately 75–80 mm overall assembly height including floor standoffs and
upper access, subject to final enclosure geometry. Support the 195 g supply
without excessive board flex. Keep exactly four aligned mounting columns.

The retained IRM-45-12 sets the minimum practical stack volume: 87 × 52 mm nominal
body, 88 × 53 mm source allocation and 30.5 mm maximum allocated height. The
45 mm gap leaves 14.5 mm before upper underside projections, separator and
tolerances. The MOV has a 29 × 29 mm courtyard and 26.5 mm height reserve; the
relay has a 29 × 12.7 mm envelope and 15.7 mm height. These allocations explain
the common board size; they do not establish thermal or physical assembly tests.

Use **Phoenix Contact 1868076 (MKDS 5/2-7,62)** fixed side-entry screw
terminals on lower-board J1–J4. Each uses both positions. Their bodies are
15.24 × 12.5 × 21.5 mm, below the existing 30.5 mm supply height allocation.
Reserve 35 mm outward wiring access; top screw access requires removing the
controller and separator with mains disconnected. Lower J5/J6 retain right-angle
Micro-Fit mating, latch release and withdrawal paths outward from accessible
edges. Controller service J2 is JST S2B-XH-A, physically distinct from the
12 V Micro-Fit ports. Separate filter LINE/LOAD wiring. Controller buttons,
USB and test points remain accessible from above or an edge.

Preserve the controller antenna overhang and 15 mm three-dimensional reserve
from lower components, copper, wiring, conductive hardware and enclosure walls.
The intact dielectric separator has a separately recorded 11.1 mm antenna gap;
its RF influence remains unmeasured. Keep the inner controller
ground reference and USB geometry in [the stack contract](design/controller-stackup.md).
Retain an insulating separator between mains and controller with mechanically
secured supports and edges. Check primary wires, solder tails and unused metal
as well as board copper against the existing 8 mm primary-to-SELV and 3.2 mm
different-primary-net requirements. Spacer length alone is not insulation
acceptance. Keep ventilation and final-unit temperature checks for the stack.

## Selected support construction

Use the [stock-material mounting construction](design/evidence/pre-fab-2026-09-14/mechanical-closure.md)
and its [manufacturer-solid CAD check](../cad/shared-enclosure/support-fit.json).
A 182 × 144 × 3 mm insulating FR-4 carrier supports the lower board on plain
7 mm spacers. Two FR-4 upper rails on four external M4 nylon rods support the
controller on plain 3 mm spacers, preserving its 45 mm clear separation. Eight
corner tabs and eight insulating edge-stop screws retain the separator without
holes or an RF notch. Use single through-bolts at PCB supports, not opposing
screws in short spacers. All PCB mounting hardware stays within the 8 mm reserves.

The four frame/base holes are at enclosure coordinates (90,55), (260,55),
(90,185), (260,185), with 4.4 mm bores. The actual base surface is Z1.8 at those
points; 3.2 mm effective feet place the carrier underside at Z5. The separate PE
bracket sits at X270..310,Y180..210,Z10..13, fastened at (275,195), (305,195).
Its central M4 PE junction uses an independently clamped metal ring stack and
an insulating cover. Base penetrations need sealing and as-built inspection.
The construction record gives stock sizes, fasteners and the complete cut pattern.

The new support/harness/enclosure interference check passes against the retained
manufacturer solid. No conductive support is added near the antenna; new dielectric
rails approach to 5.44 mm and their RF influence remains unmeasured. Mechanical
load, fastening, PE continuity, sealing and physical commissioning remain as-built
checks. The separator itself and PCB positions are unchanged.

## Enclosure and wiring

The retained enclosure candidate is **Hammond 1590ZGRP243**: 400 × 250 × 120 mm
nominal outside, 384.85 × 235.26 × 109.20 mm inside per drawing. Its unmodified
glass-reinforced polyester assembly is UL94 V-0/IP66; cutouts and glands require
their own suitable installation. [Manufacturer](https://www.hammfg.com/part/1590ZGRP243),
[retained drawing](../cad/shared-enclosure/source/1590ZGRP243.pdf).

The [current shared CAD screen](../cad/shared-enclosure/README.md) verifies the
stack against retained manufacturer enclosure solids. Matching boards occupy
X100..250, Y65..175 mm. Lower board top is Z16.6 mm and upper underside Z61.6 mm.
The intact 158 × 118 × 2 mm separator sits at Z50.1..52.1 mm, above the allocated
supply body. Outward connector/wiring reserves extend 35 mm. The separate filter
reserve clears the enclosure by 5.40 mm nominally and 4.00 mm with the recorded
fit allowance. These are occupied-volume checks, not measured thermal or RF
performance. Final supports, glands and cable construction use this stack;
former side-by-side evidence is superseded.

The manufactured filter remains beside the stack with separate dirty LINE and
clean LOAD routing, away from sensor wiring and the ESP antenna. Preserve its
terminal and wire-bend allocation; board size is not the complete mains assembly
footprint. Use insulating carriers rather than a common steel panel. Keep mains
terminations inaccessible, provide strain relief and drip management, use GFCI
protection, and retain continuous PE to the filter case, output and any conductive
parts requiring bonding. Disconnect mains before opening or servicing.

Place the enclosure on the available flat surface behind the tank with its sensor
connection within the **203.2 mm complete harness limit**, including internal
routing. No old enclosure rotation, gland coordinate or 60 mm internal allowance
is an accepted measurement for this stack. Final strain relief and cable geometry
must establish reach without pulling the sensor off the glass.

## Sensor adhesive interface

Use the **18 × 64 mm** four-layer sensor entirely below the rim on the outside of
5 mm freshwater aquarium glass. Top edge is 2 mm below the rim; water is at least
10 mm below it. The mask-covered B.Cu sensing face adheres to glass with thin,
uniform mounting tape or transfer film. No clip, rail, bracket or mounting plate
sits between PCB and glass. Avoid foam and trapped air; the owner selects tape
and its installed thickness becomes part of final calibration.

Electronics and six pigtail solder lands face outward. The cable exits left when
viewed from outside, with outward-side strain relief. Anchor its jacket to adjacent glass using two
nonconductive tie bases with VHB 5952 and a relaxed bend to J1, as specified in
the mounting construction. Keep foam tape under those external anchors only.
Preserve a flat glass-facing
surface without exposed solder, through-hole connector tails or mounting holes.
The [sensor specification](sensor.md) defines the 50 mm physical electrode span
and lower wet reference. The accepted image remains a visual reference, not a
claim of measured sensitivity, adhesive durability or usable travel.

Protect the board from splashes and cable loads. Measure gap/adhesive effects,
replacement repeatability and final calibration on the assembled unit. No owner
clip CAD is required. This project owns its board/adhesive/pigtail interface.

## Verification boundary

Use current source/native placement, planes, routing rules and rendered geometry
before routing. Final routed ERC/DRC and manufacturing checks remain mandatory;
actual temperature, skimmer interference, sensor calibration and mounting durability
remain commissioning tests. A source or CAD screen cannot pass those measurements.

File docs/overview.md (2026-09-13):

# System overview

Crystal Shim monitors aquarium water level through the outside glass and controls
an OASE CrystalSkim 350. It runs for a configurable 15 minutes a few times daily
when enough water is present. Automatic low-water stop/recovery and timed HomeKit
switch overrides are confirmed requirements. Every run ends automatically; an
explicit override can run at a valid low level. See [the control contract](controls.md).

The project targets one complete, final-use three-board build. There is no separate
sensor prototype or planned PCB revision cycle. Resolve geometry, interfaces and
component selection through reference research, calculations and design review
before fabrication; calibrate and verify actual performance on the final assembly.
See [the build sequence](build.md).

The present boards must reserve the [future refill expansion interface](design/refill-expansion.md)
before fabrication. Three future pump drivers and two sensor ports belong on the
controller; the mains board supplies fixed 12 V accessory power and regulated 5 V
base power. Only accessories and a reservoir sensor board are added later. The
refill/conditioning feature remains deferred; its specification stays in the linked
Executor artifact.

The North American skimmer is specified at 120 VAC, 60 Hz, 4 W. Starting behavior
must be accounted for in relay and fuse selection from documented ratings and
design margins, then measured during final-assembly commissioning.
[OASE product specifications](https://www.oase.com/en-US/aquarium/crystalskim-350).

## Three boards

| Board | Location | Responsibility |
| --- | --- | --- |
| Sensor daughterboard | Outside aquarium glass | Continuous level electrode, wet reference and stored dry baselines, FDC1004, local 3.3 V regulation |
| ESP controller | Low-voltage enclosure section | ESP32-C6, 3.3 V rail, USB programming, relay driver, three reserved pump drivers, two sensor ports, status LED, maintenance button |
| Mains board | Mains enclosure section | Protected input, isolated PSU, relay contacts and coil, pump output suppression |

The sensor is 18 × 64 mm with common-net horizontal sensing bars, thin adhesive
mounting entirely below the rim and a left-exiting pigtail. The controller and
mains boards share 150 × 110 mm outlines and aligned M3 mounts; the controller
sits above mains with 45 mm clear separation. See [mechanical design](mechanical.md)
for the retained visual references and exact interface requirements.

The manufactured two-stage EMI filter sits alongside the mains board. The PSU is
always powered when mains is present, regardless of relay state. Its secondary
and the relay coil occupy a defined low-voltage region on the mains board; their
connections to the controller cross no exposed mains conductors.

```mermaid
flowchart TD
  IN[120 VAC input] --> PROTECT[Fuse and protected surge suppression]
  PROTECT --> PSU[Isolated 12 V PSU and 5 V buck on mains board]
  PSU --> ESP[ESP controller board]
  ESP -->|5 V and 3.3 V I2C, cable at most 8 inches| SENSOR[Active sensor daughterboard]
  PROTECT --> FILTER[Two-stage manufactured EMI filter, L and N]
  FILTER -->|filtered hot| RELAY[Normally-open relay contact]
  RELAY --> OUT[Switched skimmer output]
  FILTER -->|filtered neutral| OUT
  ESP -.->|low-voltage coil driver| RELAY
  OUT --- RC[Series RC network across switched L and N]
```

PE is omitted from the functional diagram. It runs continuously to the filter case,
output earth where present, and exposed conductive parts requiring bonding. Never
switch PE. Neutral is not switched alone; the relay interrupts hot.

The ESP and sensor are galvanically isolated from mains. The pump is filtered and
switched but **not galvanically isolated** from household power. No isolation
transformer is included. USB connects to the isolated low-voltage domain only.

Moving the capacitance converter onto the sensor keeps analog capacitance traces
short. The cable carries power and digital data rather than sensitive electrode
signals. The first interface may expose LOW / NORMAL / HIGH; millimeter accuracy
is not a requirement.

No routine sensor cleaning is the acceptance goal. Outside mounting removes an
immersed mechanism but does not prove immunity to films or deposits inside the
glass. The actual aquarium and interference setup must be tested.

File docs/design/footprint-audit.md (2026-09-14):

# Physical component capture audit

The current authoritative source captures 113 controller components, 22 mains
components and 16 sensor components. Counts include 14 controller test pads and
the sensor electrode copper structure. Exact purchased MPNs and board-qualified
reference designators are grouped in the [BOM](../../bom/bom.csv). Current native
adoption and routing status are recorded in [STATE](../STATE.md); this source audit
does not declare fabrication or routing readiness.

This revision supersedes the earlier TPS259470 and LT3042 footprint selections.
Neither eFuse, its threshold network, the LT3042 exposed-pad/SET/PGFB network nor
the live RE/OoP_RE electrodes are populated. Their historical source receipts do
not authorize adding them back. Ordinary logic pullups, pulldowns and series
resistors use 1% ERJ parts; the PSU supervisor divider retains precision ERA parts.

## Controller

- ESP32-C6-WROOM-1-N8 follows the manufacturer's numbered module pads and antenna
  exclusion. The native footprint origin is 3 mm below the body centre. Retain
  nine separate exposed-ground lands and their paste apertures.
- AP63203WU-7 uses its TSOT26 manufacturer mapping and SRP5030TA-4R7M inductor.
  It has no exposed ground pad. Regulator bypass placement and quiet feedback
  remain routing obligations.
- GCT USB4105-GF-A uses the manufacturer's body datum and alphanumeric contacts.
  Compiler indices 1–17 are not physical contact numbers. Restore contact names
  and normalize the adapter bounds-centre to the GCT body origin before native
  conversion. Shared shell/ground contacts remain grounded.
- The USB ground-pad R0.25 corner adaptation preserves pad centres and overall
  bounds while clearing the locator holes. Its geometry, stack and impedance
  evidence remain in [controller stackup](controller-stackup.md).
- AO3400A uses gate/source/drain pads 1/2/3. Q1 switches the relay coil; Q2–Q4
  switch future motors. STPS2L40U uses cathode pad 1 and anode pad 2. D9–D11
  connect cathode to 12 V and anode to each motor drain.
- TCA9517ADGKR and ESDS312DBVR are captured for each of the two sensor ports.
  Both buffer supplies are 3.3 V, cable on A and ESP on B. Shared sensor power
  retains TPS2553DBVR, with separate passive branch filtering.
- Molex 43045-0200 headers serve the 12 V feed and motor outputs. Controller
  service J2 uses JST S2B-XH-A with XHP-2 housing and SXH-001T-P0.6 contacts,
  making the 5 V interface physically distinct. Both service pins are used.
  Assembly labels and pin-1 polarity must match the wiring drawing.
  Two 43045-0600 headers on the controller share one electrical sensor pinout;
  the tank sensor uses six numbered solder lands for its pigtail instead of a
  header. 43650-0300 carries the 5 V/return/coil harness.
- TP1–TP14 are PCB copper, not purchased components. TP12/TP13 expose GPIO4/5,
  and TP14 provides their nearby return; TP11 remains the UART service ground.

## Mains

IRM-45-12 uses its manufacturer 87 × 52 mm body and numbered primary/secondary
pins. AP63205WU-7 generates the 5 V base rail using the same buck package family
as the controller. The 3 A motor-branch fuse is 0451003.MRL; the 1 A filter branch
uses axial 0215001.MXEP. The separate inlet F1 is a 2 A 0215002.MXP cartridge,
not a PCB placement.

G5RL-1A-TV8 DC5 retains the manufacturer coil/contact mapping and contact stagger.
TMOV14RP175E uses the bulk straight-lead part and the existing installed envelope.
The enlarged 4.5 x 1.3 mm slot captures the full published lead spacing without
forming; see the [MOV capture](mov-capture.md) and current ECO evidence.
B32921C3473K000 is the 47 nF X2 snubber capacitor; PR02FS0201000KA100 is its
100 ohm flameproof resistor. Formed leads and installed bodies must fit the
captured assembly envelope. 1N4007-E3/54 is the relay-coil flyback diode.

J1–J4 each use a Phoenix Contact 1868076 fixed side-entry screw terminal block.
Each has two used pins at 7.62 mm pitch, with 1.3 mm holes and 3.5 mm copper
lands. There are no unused contacts or cable housings. The body is
15.24 × 12.5 × 21.5 mm. Refer to the
[mains design basis](mains-design-basis.md) and actual manufacturer drawings.

## Sensor

FDC1004DGSR uses the DGS VSSOP-10 mapping. CIN1 receives LEVEL, CIN2 wet RL;
CIN3 and CIN4 are open and CIN4 is the differential negative input. The E1
structure contains LEVEL/RL and their opposite-phase shields, without live RE.
The [sensor design basis](sensor-design-basis.md) owns electrode dimensions and
layer assignments.

TPS7A2433DBVR is the fixed 3.3 V SOT23-5 regulator. STPS2L40U connects output
anode to input cathode for source collapse. Exact 10 µF input/output, FDC bypass,
bleeders, signal resistors and ESDS312 protection remain source-populated; no
LT3042 pinout or PGFB diode applies to this board.

## Geometry and downstream verification

Manufacturer drawings commonly use positive Y down; source uses positive Y up.
Convert once. Preserve physical pad names, body datums and source identities
through export. Current physical declarations include F.Fab bodies, closed
courtyards and explicit mask/paste geometry. The project courtyard starts 0.5 mm
outside the combined copper, NPTH and package envelope, rounded outward to
0.05 mm. A courtyard is an assembly planning envelope, not an electrical spacing
waiver. Default NSMD expansion is 0.05 mm unless the exact package declares a
different reviewed geometry.

Before native acceptance, compare source/exported pad numbers, positions, shapes,
holes, polarity and net connectivity; inspect schematic and physical renders,
then run strict schematic ERC and pre-route DRC. Check connector mating and wire
access against the [current enclosure](../mechanical.md). Routing must preserve
mains separation, sensor shields, USB reference and compact motor return paths.
Source tests and static fit checks cannot measure actual interference, thermal
behavior or sensor performance. No fabricated or energized evidence is claimed.

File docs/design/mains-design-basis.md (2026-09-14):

# Mains board and enclosure design basis

Current source design, 2026-09-12: a shared 12 V supply supports the existing
skimmer interlock and the future refill interface. The extension behavior remains
outside this hardware capture; see [refill expansion](refill-expansion.md) for the
artifact reference and reserved interface. No independent extension adapter is required.

## Selected architecture

```text
IEC inlet L -> F1 T2A -> J1.1 AC_L_FUSED -> U1 IRM-45-12 AC/L
IEC inlet N ----------> J1.2 AC_N -------> U1 AC/N
AC_L_FUSED -> RV1 TMOV -> AC_N
AC_L_FUSED -> F3 T1A -> FILTER_LINE_L -> J2.1 -> filter LINE L
AC_N ---------------------------------> J2.2 -> filter LINE N
filter LOAD L -> J3.1 -> K1 contact 3
filter LOAD N -> J3.2 -> J4.2 -> pump neutral
K1 contact 4 -> J4.1 -> pump hot
J4.1 -> R1 100 ohm -> C1 47 nF X2 -> J4.2

U1 +V -> V12_RAW -> F2 3A -> J6.1 V12_MOTOR -> controller motor feed
U1 +V -> AP63205 fixed buck -> V5_PSU -> J5.1 and K1 coil 1
U1 -V -> GND_ISO -> J5.2 and J6.2
K1 coil 5 -> J5.3 COIL_DRAIN -> controller relay MOSFET
D1 cathode -> K1.1; D1 anode -> K1.5

IEC PE -> dedicated PE star -> filter case and output pigtail PE
```

The supply remains outside the skimmer EMI filter. Neutral and PE are never
switched; PE has no PCB trace or pluggable PCB dependency. K1 is normally open.
Loss of coil power opens hot but cannot cure welded contacts. No mains energizing,
purchase or fabricated-board performance is implied by source checks.

## Isolated supply and power budget

Select **Mean Well IRM-45-12**, 12 V, 3.8 A, 45.6 W. The
[manufacturer specification](https://www.meanwell.com/Upload/PDF/IRM-45/IRM-45-SPEC.PDF)
(2025-11-21) gives 85–305 VAC input, full rated output through 50 C at at least
100 VAC, typical 87.5% efficiency, 30 A cold inrush at 115 VAC and 60 A at 230 VAC.
Overload is 115–160% hiccup; OVP operates at 12.6–16.2 V. Those limits describe
the source protection, not a precisely limited accessory output.

Keep the existing **850 mA allocation at 5 V**: relay 110 mA, controller converter
635 mA, sensor supply 30 mA, reserve 75 mA. Two 10 mA sensor allocations fit that
30 mA allowance. This 4.25 W load needs 5.3125 W from 12 V at the deliberately
conservative 80% buck efficiency used for budgeting. Sensor/controller peaks and
startup charging remain inside this base allocation until measured.

| Combined demand | Conservative calculation | Share of 45.6 W |
| --- | --- | ---: |
| 2 A continuous motor allocation plus base | 12.54 V × 2 A + 5.3125 W = 30.3925 W | 66.7% |
| 3 A brief aggregate motor startup plus base | 12.54 V × 3 A + 5.3125 W = 42.9325 W | 94.2% |

The 11.46–12.54 V normal design envelope includes 2.5% total tolerance, 150 mVpp
ripple and 0.03%/C temperature drift over 0–50 C. It is a conservative arithmetic
allocation, not measured output. The 3 A startup target has limited headroom;
confirm actual selected pump pulses, no sustained aggregate overload, repeated
starts and no controller brownout on the final assembly. The 2 A allocation is
**total for all three future pump channels**, not per connector.

### IRM-45-12 footprint

The module body is 87 × 52 × 29.5 mm with general ±1 mm drawing tolerance and
195 g mass. Reserve 30.5 mm body height above its seating plane. It is larger and
heavier than the superseded IRM-10-5. The source footprint mirrors the manufacturer's
bottom view about 87 mm into component-side coordinates (+X right, +Y down):

| Source pin | Function | Component-side X,Y mm | Finished drill / copper mm |
| --- | --- | --- | --- |
| 1 | AC/N | 5.3, 11.75 | 1.5 / 3.0 |
| 2 | AC/L | 5.3, 5.0 | 1.5 / 3.0 |
| 3 | -V | 81.3, 40.75 | 2.5 / 4.5 |
| 4 | +V | 81.3, 46.25 | 2.5 / 4.5 |

Manufacturer terminals have functions rather than source pin numbers. AC leads
are 1 mm diameter, DC leads 2 mm, projection 3.5 ±1 mm. Finished drills and copper
are declared project allowances; preserve the exact source geometry on export.
The manufacturer's PDF SHA-256 is recorded in `power-components.tsx`.

## Five-volt conversion and coil interface

Use **Diodes AP63205WU-7**, fixed 5 V/2 A synchronous buck in TSOT26. Its
[manufacturer datasheet](https://www.diodes.com/datasheet/download/AP63200-AP63201-AP63203-AP63205.pdf)
DS41326 Rev 3-2 specifies 3.8–32 V input, cycle current limiting, hiccup short
protection, thermal shutdown and soft start. Pin 1 FB senses V5_PSU after L1;
pins 2 EN and 3 VIN use V12_RAW; pin 4 is GND; pin 5 SW drives L1; pin 6 BST
connects through C5 100 nF to SW. L1 is Bourns SRP5030TA-4R7M, 4.7 µH.
C2/C3 are Murata GRM32ER71E226ME15L, 22 µF/25 V, in parallel at the
input; C4/C6 are the same output pair. C7 is 100 nF/50 V at VIN. Retain this
ordinary capacitor population. [Analog Devices' MAXREFDES1101](https://www.analog.com/media/en/reference-design-documentation/reference-designs/maxrefdes1101.pdf)
uses this exact Murata family at 12 V and budgets 60% capacitance reduction from
DC bias. For this 12.54 V upper-normal input, use a more conservative **65% bias
loss**, then 20% initial tolerance and 15% X7R temperature loss:
`44 µF ×0.35 ×0.80 ×0.85 = 10.472 µF`. That remains above the Diodes 10 µF
input recommendation. This is a disclosed design allowance using a published
application, not a manufacturer-guaranteed minimum capacitance curve.

At 850 mA output and nominal 1.1 MHz, the bank's maximum ideal input ripple is
`I/(4 f C) = 18.5 mVpp`; maximum bank RMS current is `I/2 = 425 mA`. Keep both
parts and C7 close to VIN/GND. The output pair is the recommended 2 ×22 µF, at
lower DC bias. Retain normal final-unit ripple/transient/thermal commissioning;
no extra capacitor or protection bank is needed for source capture.

The datasheet gives 4.95–5.05 V in CCM across its specified temperature/input
range. Use **4.8–5.2 V** as the project normal-rail acceptance allocation, leaving
150 mV each way beyond the static limit for ripple and dynamics. It is not a
guaranteed PFM/transient specification. Nominal CCM calculation at 12.54 V,
4.7 µH and 1.1 MHz gives 0.58 A inductor ripple and about 1.5 mVpp ideal
capacitive output ripple with 44 µF, before ESR/bias/tolerance. Measure final
load transitions and repeated starts against the chosen envelope.

The previous TPS259470 cutoff, precision dividers, ramp parts, bleeder and clamp
are removed. Ordinary operation uses the protected converter and known 5 V coil.
There is no independent buck-failed-high disconnect. A failed-short buck could
expose the coil to 12 V; the retained flyback diode is not supply-overvoltage
protection. The AP63205 itself accepts the module's 16.2 V OVP maximum; 25 V input
capacitors retain voltage margin. The controller and sensor input ratings are
owned by their respective design bases. Existing hardware PSU_GOOD remains the
controller's coil-supply presence condition.

Keep Omron **G5RL-1A-TV8 DC5** and Vishay **1N4007-E3/54** flyback. Omron's
[terminal drawing](https://omronfs.omron.com/en_US/ecb/products/pdf/en-g5rl.pdf)
uses coil 1/5 and NO contacts 3/4; the source component-side positions are
1=(23.5,0), 5=(23.5,7.5), 3=(0,0), 4=(3.5,7.5) mm. Preserve the 3.5 mm contact
stagger and 1.3 mm finished drills. Coil pickup/dropout at enclosure temperature
and opening transients remain commissioning checks. Flyback may delay release.

J5 stays Molex **43650-0300**, mating **43645-0300**, contacts **43030-0007**:
1=V5_PSU, 2=GND_ISO, 3=COIL_DRAIN. Preserve the existing 22 AWG red/black/blue
harness. J6 uses **43045-0200**, mating **43025-0200**, contacts **43030-0007**,
1=12 V motor positive and 2=return. Use 20 AWG for that short internal 2 A feed.
Both isolated harnesses cross the enclosure partition. Label the 12 V harness at
both ends and keep it distinct from the service input during assembly and service;
this internal harness does not require a new incompatible connector family.

## Fuse, surge and relay-load suppression

F1 is **Littelfuse 0215002.MXP**, 215-series T2A, 250 VAC ceramic cartridge,
in the existing fused IEC inlet. F3 is board-mounted **0215001.MXEP**, the
same series T1A axial version, ahead of J2/filter LINE. This branch fuse preserves
a 1 A pump/filter branch without passing the larger shared PSU current through it.
The [215 datasheet](https://www.littelfuse.com/assetdocs/littelfuse_fuse_215_datasheet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)
gives 1.5 kA interrupt rating at 250 VAC; nominal melting integrals are 11.68 A²s
for T2A and 1.52 A²s for T1A. These are not full clearing-energy guarantees or
proof of selective coordination. Repeated source inrush must not nuisance-open F1.

F3 uses a declared 30.48 mm formed-lead pitch, 1.1 mm drills and 2.5 mm copper.
The axial body is 21.5 ±1 mm long, 5.5 ±0.3 mm diameter; 0.65 ±0.05 mm leads.
Keep the body at least 1.5 mm above PCB and bends more than 1 mm from its caps.
Hand-solder after SMT, 350 ±5 C for at most 5 s. This removes a fuse-holder or
extra harness assembly, at the cost of desoldering for replacement. Mains cord
removal is required before enclosure access or fuse replacement.

F2 is **Littelfuse 0451003.MRL**, 451-series 3 A fast SMT, in the 12 V motor feed.
The [451/453 datasheet](https://www.littelfuse.com/assetdocs/fuse-451-and-453-datasheet?assetguid=533cd5cc-956c-4243-867f-6ab5a62f6ba1)
gives 125 VAC/VDC, 300 A interrupt at 32 VDC, 0.0227 Ω nominal cold resistance,
4 h minimum hold at rated current and 5 s maximum opening at twice rating.
At 2 A the nominal cold loss is 91 mW. The 2 A load is below the manufacturer's
75% continuous-current recommendation for a 3 A fuse at room temperature;
confirm its temperature derating and actual startup pulses. A fuse is not a
3 A current limiter. IRM hiccup may occur before F2 opens; base-power availability
during a motor short is not promised. Do not add a second eFuse bank.

Retain **TMOV14RP175E** across fused line/neutral at J1, with its
[existing source/installed-envelope contract](mov-capture.md). F1 carries its
surge/fault current. Retain the load-side **PR02FS0201000KA100** 100 Ω flameproof
2 W resistor and **B32921C3473K000** 47 nF/305 VAC X2 capacitor. The RC bridges
switched hot to filtered neutral and has no open-relay bypass path. The source suppression models preserve their exact part geometry and pulse basis.

## Mains harness, filter and enclosure

Keep TE/Schaffner **FN2090A-1-06** (802490-SF), rated 1 A at 40 C. Its temperature
curve must be respected above 40 C; the supply's 50 C capability is not the
filter's current rating. Keep LINE and LOAD pairs apart. The OASE CrystalSkim350
120 V/60 Hz/4 W label does not publish RMS current or motor startup current.
Commission actual current, starts and relay opening behavior; 4 W/120 V is only
unity-power-factor current, not a fuse-selection measurement.

J1/J2/J3/J4 each use **Phoenix Contact 1868076, MKDS 5/2-7,62**, a fixed
side-entry screw terminal with two used circuits: 1=line, 2=neutral. There are
no unused pins, pluggable housings or separate crimp contacts. Each circuit has
one solder tail. See the [terminal capture basis](mains-header-capture.md) for
geometry and assembly instructions. Label both ends of each wire by function;
fixed wiring removes the old unproven cross-mating scheme but still requires
correct assembly and continuity checks.
Keep the selected Schurter inlet/cord, insulated TE 2-520184-2 Faston terminals,
Americord 1112.048.005350 output pigtail and Heyco M3231 gland described in the
[harness specification](../electrical.md). Do not alter the pump's original cord.

The source board is **150 × 110 mm**, two layers, nominal 1.6 mm FR4. Four 3.2 mm
mounts are 7 mm from each edge, matching the controller above at 45 mm clear
board-face spacing. See the [canonical stack](../mechanical.md). The old 135 ×75 mm screen and Hammond1554V2GY
arrangement are superseded; they are not evidence that the new shared-supply
assembly fits. Use the revised enclosure allocation and preserve the mains/SELV
partition, 8 mm primary-to-isolated and 3.2 mm different-primary-net clearance
requirements. Complete mated connector occupancy, mounting metal, wire bend access,
all-layer routed clearances and final temperature still need native/assembly review.

## Capture and acceptance

Source capture contains 22 electrical parts, 53 logical pins, 53 numbered lands
(31 PTH, 22 SMT), 14 named nets, 53 connected endpoints, no NC pins,
and six NPTHs. See [placement](mains-placement.md),
[thermal/stencil](mains-thermal-stencil.md) and [native handoff](mains-native-handoff.md).
The source and in-memory converter checks do not establish a routed clearance,
clean native ERC/DRC, fuse coordination or assembled thermal performance.

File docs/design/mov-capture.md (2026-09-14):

# Thermally protected MOV capture

Use **Littelfuse TMOV14RP175E**, the stocked bulk two-lead thermally protected
175 VAC MOV, for RV1. The owner authorized the sourcing/footprint ECO on
2026-09-14. It replaces the unavailable factory-crimped TMOV14RP175EL2T7.
The electrical ratings and fused line-to-neutral connection are unchanged:
175 VAC / 225 VDC continuous, 70 J at 2 ms, 6 kA single 8/20 us surge and
455 V maximum clamp at 50 A. It retains its internal thermal disconnect and
the separate upstream fuse. See the [mains basis](mains-design-basis.md).

## Unformed lead capture

The [Littelfuse family datasheet](https://www.littelfuse.com/assetdocs/tmov-itmov?assetguid=bd475732-1071-4352-b8aa-f78b0007eb05),
revision 10/15/25, gives bulk lead spacing components e=6.5..8.5 mm in the
disc plane and e1=1.5..4.0 mm transverse, and lead diameter 0.76..0.86 mm.
The lead-pair length is therefore 6.670832..9.394147 mm. Rotate the upright
part to align its two unbent leads with the hole/slot axis; do not reshape them.

| Feature | Source-local centre | Finished drill | Copper |
| --- | --- | --- | --- |
| Pin 1, fused line | (0, 0) mm | 1.3 mm round | 2.9 mm round |
| Pin 2, neutral | (7.9, 0) mm | 4.5 x 1.3 mm plated capsule | 6.1 x 2.9 mm capsule |

The slot and copper extend 0.8 mm only to the right of their former outlines.
Their left edges and the 3.4 mm nominal inter-pad copper gap remain unchanged.
The fit calculation conservatively allows finished hole/slot size tolerance
+/-0.15 mm and differential centre error at most 0.15 mm.
[JLCPCB standard capabilities](https://jlcpcb.com/capabilities/pcb-capabilities)
list plated hole/slot +0.13/-0.08 mm and hole position +/-0.05 mm. The calculation
covers those published limits, including a 0.1414 mm diagonal differential error
if the position tolerance applies independently to X and Y. No tighter custom
tolerance is requested. At maximum lead diameter, the worst-size available longitudinal
movement is (1.15-0.86)/2 + (4.35-0.86)/2 = 1.89 mm. Including centre error,
permitted lead spans are 6.16..9.64 mm. Minimum and maximum lead-pair spans have
0.510832 and 0.245853 mm margin respectively. Worst yaw is atan(4/6.5)=31.608
degrees; a conservative transverse position-error allowance adds 1.289 degrees.
The 35-degree installed yaw limit covers this without lead bending or body lean.
Source tests check both span extremes, all published spacing corners, rotation,
exported slot geometry and unchanged left copper/drill edges.

## Installed assembly contract

The source courtyard and placement reserve stay centred at local (3.75, 0) mm,
not at the new hole/slot midpoint. This preserves the existing placement allocation.

| Requirement | Limit |
| --- | --- |
| Entire body, coating, leads and solder at every height | 27 x 27 mm XY centred at local (3.75, 0) |
| Placement reserve | 28 x 28 mm, top at most 26.5 mm above PCB |
| Courtyard | 29 x 29 mm |
| Installed top | At most 26.0 mm above PCB |
| Supported body seating above PCB | 0.5..1.0 mm |
| Tail and solder below actual board underside | At most 2.0 mm |
| Upright part yaw relative to pad axis, modulo 180 | At most 35 degrees |
| Lean from upright | At most 5 degrees |

The manufacturer bounds body diameter at 17 mm, thickness at 9 mm and height A
at 22 mm for this part. It does not fully locate the body relative to the leads.
The lead-fit proof is not a universal occupied-body guarantee. The same whole-volume
final-unit inspection remains required; the part must fit loosely without loading
the coating. All acceptance limits include measurement/fixture error. Preserve
3.2 mm mains-net clearance and the separate 8 mm primary/secondary barrier,
including trimmed leads and solder. Do not enlarge the solder envelope into these gaps.

Use a removable fixture to support the unformed part independently while soldering.
Keep it upright, adjust its yaw to the supplied lead stagger, and do not force the
leads into the holes. Inspect the unpowered fit before soldering and after fixture
removal. Hand solder after reflow with independent lead heat sinks. No stencil paste
or permanent adhesive/support is added. These instructions replace the obsolete
crimp-seat procedure; this bulk part has no factory crimp to seat against the PCB.
Actual solder-process, fit and operating tests remain commissioning evidence.

## Evidence

[Current ECO](evidence/mov-bulk-eco/) records source/native parity, preservation,
DRC, renders and fabrication review. The [previous capture](evidence/mov-bulk-eco/previous-mov-capture.txt)
retains the earlier L2T7 analysis as history, not as the assembly instruction.
The [sourcing review](../../bom/mov-sourcing-2026-09-14.md) records why the part changed.

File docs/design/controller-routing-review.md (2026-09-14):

# Controller routing review and USB decision

Reviewed 2026-09-14. The owner accepts USB full-speed (12 Mbps) F.Cu/B.Cu routing,
including the connector crossover and paired through-via transitions. No paid
impedance control or 81-99 ohm fabrication acceptance is required. The prior
F.Cu-only/no-via, exact gap, 0.5 mm mismatch and mandatory side-ground/stitch-pitch
criteria are superseded for these reviewed paths. USB90 remains a routing-default
name, not a claim of measured or guaranteed impedance. Actual USB operation remains
a final-board commissioning check.

Independent power and ground reviews found no functional routing blocker. Buck
loops and ESP decoupling are compact; 3V3 uses In2 distribution; motor drivers
have nearby ground-via groups. In1 and B.Cu each have one continuous ground fill;
all nine F.Cu regions connect, including J4's contact regions through its plated
shield pads. No concrete USB functional issue or long open stub was identified.

The two requested fixes were verified from fresh saved native geometry:

- V5_SERVICE now has parallel 0.6/0.3 mm vias at (78,112) and (77,111), connected
  on F.Cu and B.Cu. This service feed excludes motor and relay-coil current.
- The unused V3V3 via at (52,77.5) is removed.

The release reconciles the native rules and routing checker with this decision,
declares the exact added V5_LOGIC pour and replaces the legacy fabrication note.
Fresh final routing checks report **zero findings and zero unconnected items**.
The former 21 USB and two service-via policy findings are removed through the
reviewed rule changes, without changing traces, vias or clearances.

The [combined pre-fabrication review](evidence/pre-fab-2026-09-14/) records current
validation, copper preservation, labels, procurement and CAM evidence. USB operation
still requires final-board commissioning; no signal-integrity certification or
impedance guarantee is claimed.

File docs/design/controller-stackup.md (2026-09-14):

# Controller fabrication and routing contract

The controller orders the standard four-layer **No requirement** construction,
nominal 1.6 mm FR4, 1 oz outer / 0.5 oz inner copper, green mask and
ENIG. USB operates at full speed (12 Mbps). The owner accepted the reviewed
F.Cu/B.Cu routing and through vias on 2026-09-14, with **no paid impedance
control and no 81-99 ohm fabrication acceptance requirement**.
See [the accepted USB decision](controller-routing-review.md).
The removed service eFuse requires no via-in-pad process. U1 uses
four **0.20/0.45 mm tented ground vias** with no added paste apertures.

These are reviewed design choices for native layout. They are not fabricated
measurements or an accepted board order. The [augmentation declaration](../../pcb/controller/design/kicad-augment.json)
records application and verification obligations; every native operation still
needs saved-board evidence. No routing, detailed stackup or thermal/paste
augmentation is complete merely because it appears in that declaration.

## Retained native stack basis

The prior adopted [KiCad project](../../pcb/controller/kicad/README.md) contained
the reviewed copper/dielectric thicknesses, material labels and Er values below,
with green mask, white silk and ENIG. KiCad's GUI saved the detailed stack;
native readback verifies the basic rules and Default/USB90 routing preferences.
The current ECO must preserve and reverify these settings; current native status
is recorded in [STATE](../STATE.md). This page does not declare routing readiness.

The known nominal copper and dielectric layers sum to **1.5862 mm**. KiCad adds
its still-unverified **0.010 mm mask on each side**, giving a consistent saved
stack and native board thickness of **1.6062 mm**. The tscircuit **1.6 mm** value
continues to mean nominal ordering thickness. Do not force only the native header
to 1.6 mm while retaining a different stack sum: mechanical exports and via-length
calculations must describe the same native stack. Neither value proves the
fabricated thickness; use the selected vendor tolerance for mechanical clearance.

KiCad also retains an unverified **0.02 dielectric loss tangent**. Its dielectric
constraints flag remains disabled. These placeholders are not supplier acceptance
values and do not replace the separately recorded USB solver mask model. Their
output treatment is fixed: retain them only as CAD visualization metadata; exclude
native/Gerber-job default mask thickness and loss tangent from supplier order
constraints. The native User.Comments fabrication note now states No requirement stack,
no impedance control, no PCB assembly and tented vias without filling/capping/plugging.
The saved native note and release archive agree; native defaults are not measured values.

Basic rules now read back as 0.15 mm clearance/minimum track, 0.20 mm minimum via
drill, 0.35 mm minimum via diameter, 0.075 mm annulus, 0.20 mm hole-to-copper,
0.09 mm mask-opening-to-other-copper and 0.10 mm mask merging threshold.
The last setting merges close mask apertures when plotting; it does not independently
prove a physical 0.10 mm mask web. Default uses 0.25 mm routing width and
0.30/0.60 mm drill/pad preferences. All six USB nets use USB90's 0.24 mm width
and 0.15 mm differential gap while retaining 0.15 mm ordinary clearance.
The former **0.50 mm grounded side spacing** is historical USB design guidance.
Net-class routing preferences are not hard minimum-width enforcement.

## Stack and USB geometry

The selected vendor template is `30726297697b4c18a0946278a48fb7d8`, displayed as
`JLC04161H-7628(Standard/Finished thickness1.59mm±10%)`. Its nominal 1.6 mm ordering
selection is historical. The separate “No requirement” template has the same
published nominal layer geometry and is the current order choice. The retained
[template data](evidence/controller-stackup/selected-stackup.json) identifies it.

| Layer | Nominal thickness | Purpose |
| --- | ---: | --- |
| F.Cu | 0.035 mm | Components, signals, local ground/power |
| Pressed 7628 prepreg | 0.21040 mm, Er 4.4 | USB reference spacing |
| In1.Cu | 0.0152 mm | Continuous GND |
| Core | 1.065 mm, Er 4.6 | Symmetric four-layer core |
| In2.Cu | 0.0152 mm | Power and limited routing |
| Pressed 7628 prepreg | 0.21040 mm, Er 4.4 | Bottom spacing |
| B.Cu | 0.035 mm | Ground/thermal spreading and limited routing |

Do not rescale the pressed dielectric to force an exact 1.600 mm sum. The vendor
line solver uses **0.04064 mm finished outer copper**, while the stack table uses
nominal copper. Board thickness includes manufacturing tolerance and mask.
[JLC stackups](https://jlcpcb.com/impedance) and
[calculator guide](https://jlcpcb.com/help/article/user-guide-to-the-jlcpcb-impedance-calculator)
are the fabrication references.

The original uniform F.Cu line model used 0.24 mm width, 0.15 mm pair gap
and 0.50 mm side-ground clearance. Its recorded calculation was
[vendor calculation](evidence/controller-stackup/selected-usb-calculation.json); that model
is historical design evidence, not a prediction for the accepted routed board.
The USB90 netclass name and routing preferences may remain as useful defaults.

The owner accepts the saved F.Cu/B.Cu USB paths, connector crossover and through
vias without paid impedance control. The former F.Cu-only, no-via, exact pair-gap,
0.5 mm mismatch and mandatory side-ground/stitch-pitch requirements are superseded
for the reviewed paths. Preserve connectivity, absence of shorts, ground returns
and short connector branches. No functional failure was identified during review;
actual USB operation remains unmeasured until final-board commissioning.

## USB locator correction

The stock-derived R0.15 ground-pad corners left only **0.194403 mm** to J4's
0.65 mm locating holes, below JLC's published 0.20 mm NPTH-to-copper minimum.
Use **R0.25** on A1+B12 and A12+B1, yielding **0.218788 mm**. Preserve every pad
centre, 0.60 x 1.15 mm bound and locating hole. GCT does not specify the corner
radius; this is an explicit project DFM adaptation of its
[USB4105 B4 drawing](https://gct.co/files/drawings/usb4105.pdf).

There are four logical pad objects but two physical ground areas and two stencil
apertures. Each area changes from 0.670686 to 0.636350 mm², a 5.12% reduction.
At a 0.100 mm stencil, matching nominal paste volume is 0.063635 mm³ per area.
Shared VBUS and separate signal pads retain their existing geometry. Native
initial rules enforce 0.20 mm hole-to-copper spacing without a subminimum waiver.

USB locator and thermal-via review

## Saved stencil and assembly preparation

The selected process is a **0.100 mm laser-cut stencil** with the source-shaped,
1:1 apertures on active SMT lands. This preserves the package land patterns and
nine independent U1 ground windows; it does not reproduce TI's separate 0.125 mm
DBV stencil example. J4's four shell slots have neither front nor back paste and
are hand soldered. Overlapping USB contacts carry one aperture per physical area:
A1/A4/A9/A12 retain paste, while B12/B9/B4/B1 suppress duplicate openings. Copper,
mask, drills, pad identities and nets are unchanged.

Saved native readback and diagnostic Gerbers contain **271 front apertures and no
back apertures**. The minimum aperture area divided by wall area at 0.100 mm
thickness is **1.2275**, above the 0.66 release screen in
[Indium's stencil guidance](https://www.indium.com/wp-content/uploads/2025/03/Powder-Choice-and-Stencil-Design-Guidelines-APPNOTE-97742-R4-1.pdf).
That calculation screens release geometry, not actual paste transfer or solder
beading. Indium also discusses aperture reductions for discrete/fine-pitch parts;
this board explicitly retains its package-derived apertures instead of applying
a blanket reduction. Paste chemistry and reflow execution remain assembly-process
verification, with actual joints inspected after assembly.

Native silk now identifies all external connector functions and input pin-1
voltages, USB and RESET/BOOT/MAINTENANCE buttons. Existing test-point function
labels remain. The [pre-routing preparation evidence](../../pcb/controller/kicad/evidence/pre-routing-preparation/)
records the saved aperture readback, diagnostic plots, native DRC and acceptance.
These are preparation checks, not production fabrication files.

## Thermal copper and vias

**U2 AP63203:** reserve bottom GND beneath source X=-32..-2, Y=-5..15 mm,
600 mm² before clearances, connected to the wider ground plane. Place at least
two 0.30/0.60 mm GND vias beside each C1/C2/C3/C4/C7 ground land and two near
U2 pin 4. Keep SW compact and FB tied to the quiet output-capacitor node. There
is no exposed ground pad to invent under U2.

At 3.3 V, 0.6 A and the 80% efficiency allowance, total converter loss is
**0.495 W**. Allocating all of that assumed loss to U2 is conservative within
that assumption, not a guaranteed loss maximum. Diodes recommends 2 oz copper;
this 1 oz layout needs its own thermal acceptance. The
[AP63203 datasheet](https://www.diodes.com/datasheet/download/AP63200-AP63201-AP63203-AP63205.pdf)
quotes 89°C/W on a single-layer, 2 oz minimum-land fixture. Reusing it only as
a sensitivity example gives 94.1°C at 50°C air. Meeting the more restrictive
125°C thermal-design ceiling at that power/ambient requires an actual effective
thermal resistance below 151.5°C/W. Neither calculation measures this board.

**Future motor outputs:** route the 12 V input and common return with at least
2 mm copper width for the 2 A continuous allocation, and each 1 A output with
at least 1 mm width. Short package-pad necks need individual review. Keep each
Q/D/J flyback loop compact and return motor current directly to J6, away from
the sensor and 5 V harness return. These are routing requirements, not measured
thermal results. See the [refill contract](refill-expansion.md).

**U1 ESP module:** retain nine separate 0.8 mm ground lands and paste apertures.
Use four 0.20/0.45 mm GND vias at native x=-2.130/-0.880 and
y=-3.165/-1.915 mm, plus close returns at perimeter GND pins 1 and 28. The
interstitial drill-to-paste gap is 0.218198 mm; drill-to-existing-mask-opening
gap is 0.147487 mm. Specify top/bottom tenting and no added apertures. Do not
substitute ink plugging at this proximity under
[JLC's covering rules](https://jlcpcb.com/help/article/pcb-via-covering).
Preserve the [Espressif land pattern and antenna exclusion](https://www.espressif.com/sites/default/files/documentation/esp32-c6-wroom-1_wroom-1u_datasheet_en.pdf).

## Release evidence and commissioning

The [2026-09-14 review](evidence/pre-fab-2026-09-14/) records current native
stack/netclass, zone, via, mask/paste and routed-geometry checks, together with
exported CAM and stencil inspection. The saved copper is preserved.

Final-board commissioning still covers minimum-input/full-load regulation,
closed-enclosure radio heating, the 50°C internal-air limit, motor-branch loading,
USB operation and actual manufacturing process. The approximate 2.8 W controller
power screen excludes other enclosure loads and does not prove ambient temperature.

The independent review used the retained
[primary-source hashes](evidence/controller-stackup/review-sources.json) and
[research-source hashes](evidence/controller-stackup/research-sources.json).
Raw downloaded PDFs/HTML and solver captures remain in
`/tmp/crystal-shim-controller-stackup-research` and
`/tmp/crystal-shim-stackup-adversarial`. The checked-in extracts preserve selected
numeric evidence; they are not an assertion that every external document is
archived in this repository. No fabrication or operating release gate passes here.

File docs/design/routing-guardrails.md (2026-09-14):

# Routing with the prepared KiCad projects

Open each production `.kicad_pro`, keeping its `.kicad_dru` beside it. The boards
have filled ground copper, ground/thermal vias, and routing constraints. Component
placement follows the compact redesign; current acceptance is recorded in
[STATE](../STATE.md). Draw the remaining traces,
press **B** to refill, save, and run:

```sh
sh scripts/check-routing.sh
```

An optional board name limits the check, for example `sh scripts/check-routing.sh
controller`. Add `--final` when routing is complete to require zero unconnected
items as well. The command checks copper DRC, schematic parity and the additional
routing policy. It calculates fresh fills for checking without overwriting an open
editor. During routing, unconnected items are expected; other findings must be
resolved. Follow the [manufacturing output profile](manufacturing-output.md) for the
separate final ERC/parity, fabrication checks and export recipe.

## Copper already present

| Board | Copper arrangement |
| --- | --- |
| Controller | Four layers: F.Cu signals/ground, continuous In1.Cu ground reference, In2.Cu power/limited signals, B.Cu ground/thermal return |
| Mains | Two layers: isolated-secondary F.Cu/B.Cu ground pours, no ground pour across primary/SELV boundary |
| Sensor | Four layers: outward F.Cu electronics/signals, In1.Cu ground/limited routing, split driven SHLD1/SHLD2 backing on In2.Cu, glass-facing mask-covered B.Cu electrodes |

Prepared ground/thermal vias and pours are native-owned routing geometry. Use
actual saved zones and the current augmentation for their positions; old via
counts and coordinates are not a placement specification. The sensor's inner
driven shields are fixed electrode copper, not ground planes to refill over.

SMD pads and vias connect solidly. Ordinary through-hole pads use 0.5 mm thermal
spokes with 0.3 mm gaps. Motor-return connector pads and the mains supply return
connect solidly. Floating copper islands are removed. Existing antenna, mounting,
sensor-field and mains-barrier exclusions remain. Controller In2.Cu stays available
for power and limited signals; sensor In2.Cu has a different driven-shield role.

The controller has broad bottom copper beneath the buck, joined to the board
return rather than an isolated thermal rectangle. Final trace placement can cut
into any pour, so inspect the refilled return paths after routing. Keep motor
return paths broad and direct to their supply return; keep buck loops compact.

## High-level routing order

[Open the routing cheat sheet](https://mcp.syas.ca/boris/artifacts/art_e9fv40epjxmu078n9c).

| Board | Route first | Then | Main tips |
| --- | --- | --- | --- |
| Controller | Compact buck power loops | USB pairs, broad power/motor paths, remaining signals | Reviewed USB F.Cu/B.Cu paths and through vias accepted; keep In1.Cu ground intact; use In2.Cu/B.Cu for ordinary signals as permitted |
| Mains | Buck loops and broad isolated supply paths | Primary input/filter/relay paths, then coil/control | Keep power trunks on outer copper without vias; preserve primary/SELV gaps and separate filter LINE/LOAD paths |
| Sensor | Local regulator and decoupling | I2C and pigtail; inspect the prepared CIN/shield connections | Preserve the fixed glass-side electrodes and inner driven shields; use permitted outward/inner routing and existing field restrictions |

Refill and inspect ground returns as routes are added. Keep pair members together,
use the prepared widths, and make any narrow pad escape short before returning
to trunk width. Finish by running the final check and reviewing filled copper.

## Automatic sizes and enforced limits

The editor was verified with **Track: use netclass width** and **Via: use netclass
sizes** selected. Keep these selected, with connected-track width inheritance
disabled. Rule `opt` values keep the full trunk width even when starting at a
small pad. Select a smaller width only for a short pad escape, then return to
netclass width. DRC minimums still apply if a toolbar override is selected.

These are editor-session choices. The native board API's in-memory defaults do
not prove the GUI choices were saved; available `.kicad_prl` preferences are
reported separately by the preparation audit. Netclass values and native rule
minimums/optimums are checked from the saved project and rules. A session
preference report does not prove which width an unsaved open editor will choose.

| Route | Default / main-route minimum |
| --- | --- |
| Controller ordinary signal | 0.25 mm default; 0.15 mm fabrication minimum allows fine-pitch escapes |
| Controller 5 V rails, 12 V trunk | 2 mm |
| Controller pump drains, 3.3 V trunk | 1 mm |
| USB | 0.24 mm width / 0.15 mm gap remain defaults; reviewed F.Cu/B.Cu paths and vias accepted |
| Mains input/MOV and 12 V motor trunks | 3 mm |
| Other mains primary and 5 V trunk | 2 mm |
| Both buck switch nodes | 1 mm preferred, 0.3 mm minimum for their short lead escapes |
| Mains coil command | 0.3 mm |
| Sensor signals | 0.20 mm default; electrode geometry retains 0.15 mm minimum |
| Controller/mains ordinary through via | 0.60 mm diameter / 0.30 mm drill minimum |
| Sensor through via | 0.45 mm diameter / 0.20 mm drill minimum |
| Four installed controller module ground vias | 0.45 / 0.20 mm, only at their declared locations |

The exact power-pad approach allowances are in
[`routing-policy.json`](../../pcb/tools/routing-policy.json). Most extend 1 mm
beyond their pad; the few explicit sense/enable approaches extend 3 mm. Native
DRC uses `enclosedByArea` to require the **entire** narrow copper segment to fit
one named region. A long track merely crossing a region fails ordinary KiCad
DRC. The supplemental check independently verifies the swept copper, including
gaps between escape regions. These rules permit necks; they do not automatically
create a width transition or enlarge a small pad.

The 5 V/12 V/primary trunks and pump drains use outer copper without individual
vias. Their present current allocation does not assume that a single ordinary
signal via carries the trunk current. Ordinary signal and 3.3 V branch vias remain
available. Non-ground traces/zones cannot occupy the controller In1 reference;
signal vias may pass through it with an antipad. Blind/micro/buried vias are blocked.

USB port/switch names now end in `_N`/`_P`, so KiCad recognizes all three pairs.
Their stable source identities and endpoints did not change. The owner's
2026-09-14 [USB decision](controller-routing-review.md) accepts the reviewed
full-speed routing without paid impedance control. Native rules and the checker now permit F.Cu/B.Cu USB traces and through vias,
without the old hard pair-gap/mismatch/side-ground constraints. Width defaults
remain 0.24 mm; short/clearance/connectivity checks remain enforced. In1 stays GND-only.

Mains DRC still enforces 3.2 mm between different primary nets and 8 mm between
primary and isolated copper. The sensor field rules follow its four-layer stack and declared breakouts. Do not
apply the superseded blanket two-layer above-rim via/ground rule to this board.

## Verification and limits

Current compact-layout acceptance and final native-preparation receipts are linked
from [STATE](../STATE.md) and each board's native README. The earlier
`routing-guardrails` receipts describe the previous outlines. Native negative
checks add intentionally bad routes only to temporary project copies. The geometry
checker also tests short escapes, crossing segments and gaps between allowances.

The sensor has six exact UUID-bound exclusions for intentional In2-only shield
pads, reported by KiCad as “SMD pad has no outer layers”. The supplemental audit
checks their dimensions, net, count and layer, plus the fixed bars and breakouts.
No other padstack finding is waived. This representation has no soldermask or
paste openings on either sensor electrode layer.

Rules catch measurable geometry mistakes. They do not decide the best path, prove
motor return-current distribution, prevent all possible plane bottlenecks, or
replace the final USB/thermal/EMI review. No component, protection bank, refill
firmware or extra PCB was added. Final fabrication and physical commissioning
remain separate.

The [current validation record](evidence/compact-redesign/validation.json) includes
native checks and focused review. Generic source pin-metadata warnings and the
previously reviewed nearest-edge heuristic do not replace exact manifest/part
checks or native ERC/DRC.

Native rule semantics follow the [KiCad 10 PCB Editor manual](https://docs.kicad.org/10.0/en/pcbnew/pcbnew.html#custom-design-rules).

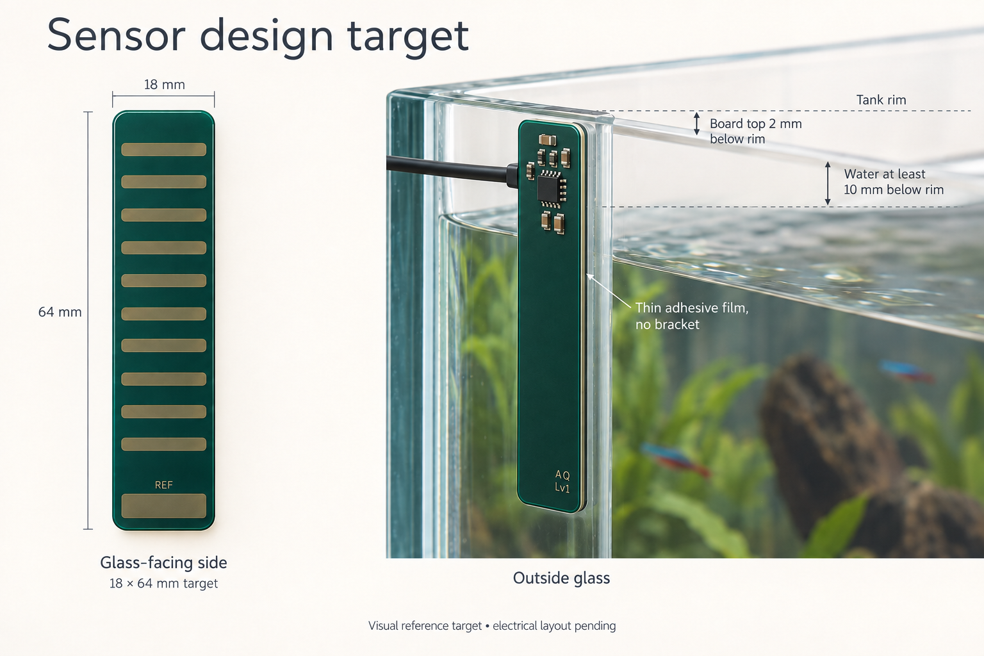
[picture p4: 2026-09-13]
docs/design/sensor-visual-target.png

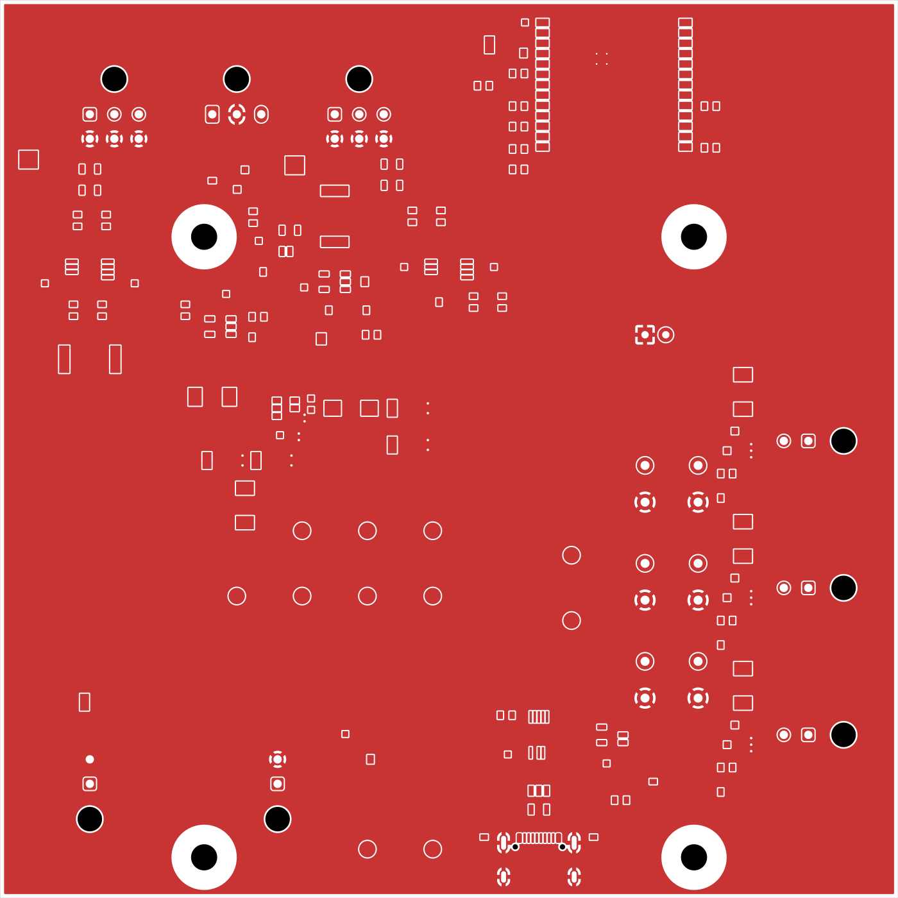
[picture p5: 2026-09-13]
pcb/controller/kicad/evidence/routing-guardrails/copper/controller-F_Cu.png

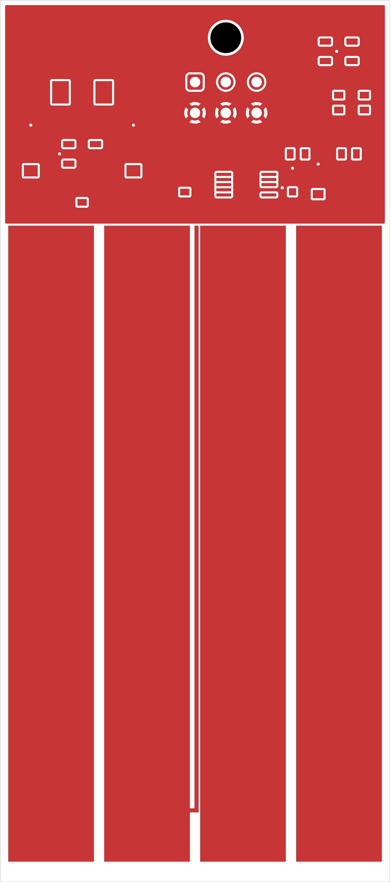
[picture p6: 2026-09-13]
pcb/sensor/kicad/evidence/routing-guardrails/copper/sensor-F_Cu.png

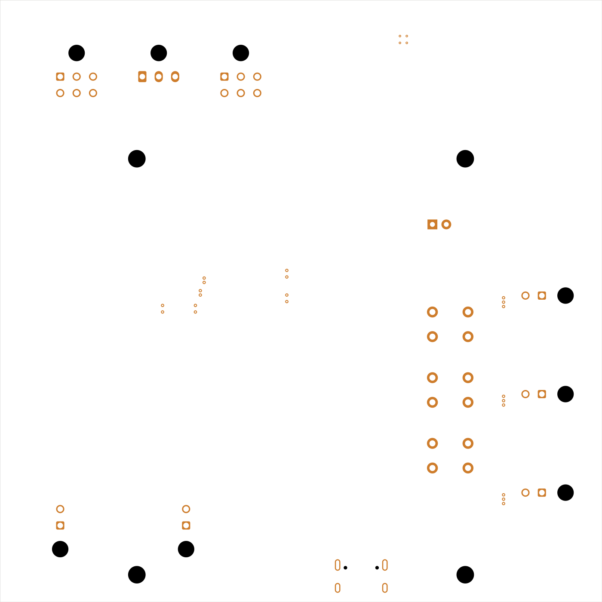
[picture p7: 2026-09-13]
pcb/controller/kicad/evidence/routing-guardrails/copper/controller-In2_Cu.png

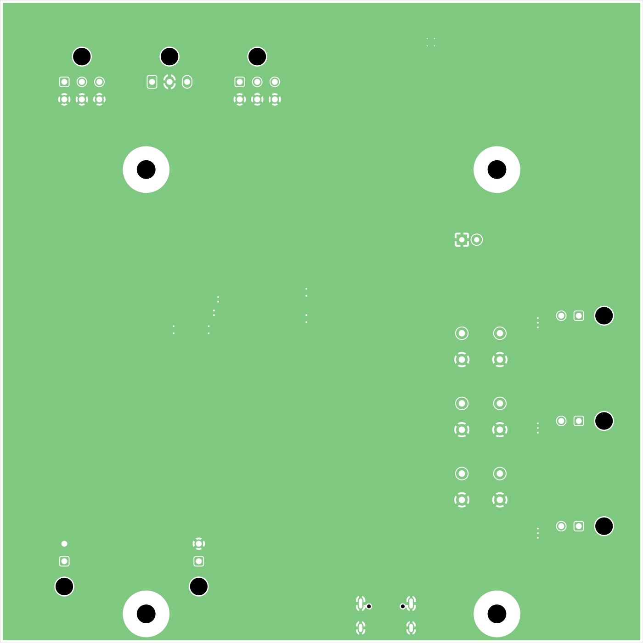
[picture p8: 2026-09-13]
pcb/controller/kicad/evidence/routing-guardrails/copper/controller-In1_Cu.png

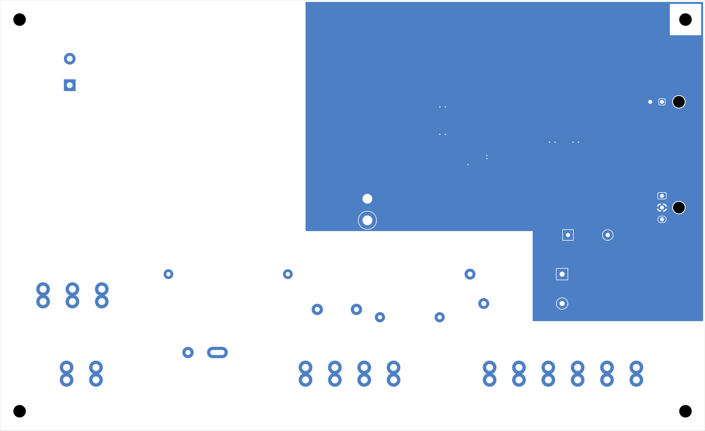
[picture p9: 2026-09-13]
pcb/mains/kicad/evidence/routing-guardrails/copper/mains-B_Cu.png

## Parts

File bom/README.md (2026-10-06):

# Bill of materials

[inventory.csv](inventory.csv) is the current purchase and stock ledger for all
103 consolidated procurement lines. Michael's owner confirmation in the procurement
reconciliation request on **2026-09-30 America/Vancouver** supersedes earlier
shipment statuses. DigiKey [101602605](purchases/101602605/README.md), all 72
order lines, and the reviewed AliExpress sensor cable are received. The cable's
purchased quantity, model and specifications remain unknown; receipt does not
confirm harness assembly. JLCPCB boards and stencils are also received; Michael
reported the PCBs in hand on 2026-10-05 without a recorded count or inspection.
[Mouser 40452969](purchases/40452969/README.md) shipped its 11 electronics on
2026-10-02 after Mouser cancelled the six-spacer line, and Michael reported receipt
on **2026-10-05 America/Vancouver**. All 103 allocations are now **In stock**.
That total reconciles earlier records with reported receipts; it is not a new
physical stocktake. The two spacer allocations are owner-held stock, not Mouser parts.
Stock quantities from received orders reflect purchased quantities; required
quantities remain distinct build allocations. Existing stock allocations do not
claim the owner's total holdings. The service supply's suitability remains unverified.

[bom.csv](bom.csv) tracks one current three-board assembly independently of
purchase status. Current source contains **113 controller components** (99 purchased
parts and 14 copper test pads), **22 mains parts**, and **16 sensor components**
(15 purchased parts plus the electrode copper structure). The grouped active PCB
rows therefore total **136 purchased placements**. Each active group lists its
board-qualified reference designators. Cable housings, contacts, enclosure parts
and the service kit are separate quantities.

Rows marked **Not populated** have quantity zero. Their stable IDs and old
selection notes remain for history; do not order them. Shared current MPNs are
consolidated into one active group, so former duplicate rows must not be added
again. Design selection does not establish native-board parity, fabrication
readiness, availability or a purchase. Purchase status and order references now
reflect the actual order above; dated fabrication and cart exports remain historical snapshots.

The present assembly includes the IRM-45-12, mains-board 5 V buck, fused 12 V
feed, three controller pump drivers, second sensor port and two input pads.
Future pumps, bottle accessories and reservoir sensor board are deferred and
must fit the [fixed attachment contract](../docs/design/refill-expansion.md).
There is no separate future expansion controller PCB in this BOM.

The known GST18U05-P1J service adapter uses a 2 A 0215002.MXP cartridge in a
01500274Z inline holder. Splice its 16 AWG leads to the selected Micro-Fit contact
wire range with insulated joints. Service power is for mains-disconnected setup;
verify polarity and delivered voltage under the [service contract](../docs/design/service-input.md).
It does not power the coil or future motors.

Exact wire lengths, assembly consumables, enclosure mounting hardware and received
mating fits still belong to assembly documentation. The current enclosure is
Hammond 1590ZGRP243; the [mechanical receipt](../cad/shared-enclosure/README.md)
records what was checked. All physical commissioning results remain unmeasured.

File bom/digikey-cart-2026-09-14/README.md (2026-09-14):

# DigiKey Canada review cart

This is the historical proposed cart. The owner subsequently purchased
[order 101602605](../purchases/101602605/README.md) with changed quantities and
two omitted lines. Use [current inventory](../inventory.csv) for purchase status.

[Open the prepared cart](https://www.digikey.ca/short/zt741mwt).
At cart preparation, no order had been placed. The link creates a copy with the same parts, quantities
and customer references; later changes to one copy do not update other copies.

Verified on 2026-09-14 in the live Canadian cart: **74 lines, CAD $586.25** before
tax and shipping. Every final line showed **Immediate** availability. Stock is
not reserved. No backorders, duplicate alternatives, full reels or assembly
services are included.

| Scope | Lines | CAD subtotal |
| --- | ---: | ---: |
| PCB components | 44 | $164.10 |
| Enclosure, harness accessories and mounting hardware | 30 | $422.15 |
| Total | 74 | $586.25 |

The quantities cover one controller, one sensor and one mains board for every
included component. Cheap passives, contacts and fasteners include practical
spares and price breaks. Expensive modules and the enclosure use single units.
The enclosure alone is $255.61. The 467MP adhesive is one 25.4 mm-wide roll, cut
into intact 18 × 64 mm sensor patches.

## Parts still needed

This cart is not a complete set of everything needed to assemble the project.
Six PCB part types could not be supplied from the checked DigiKey offers:

| Required part | Quantity | Reason |
| --- | ---: | --- |
| AP63203WU-7 | 1 | Exact and automotive Q versions backordered |
| AP63205WU-7 | 1 | Exact and automotive Q versions backordered |
| G5RL-1A-TV8 DC5 | 1 | Exact relay minimum 100; six-pin E variants do not fit |
| TMOV14RP175EL2T7 | 1 | Exact lead form unavailable at the needed quantity; no unverified lead reshaping accepted |
| TPS2553DBVR | 1 | Original, DBVT and Q1 variants backordered |
| USBLC6-2SC6 | 1 | Original ST device backordered |

The [remaining procurement list](not-in-cart.csv) also identifies the outlet
pigtail, cut wire, FR-4 sheets, sealing/support materials, PE metal hardware and
other assembly supplies. Some are available elsewhere in much more sensible
quantities. The GST18U05-P1J service adapter was omitted because the source BOM
identifies it as potentially already owned; verify inventory before buying one.
No private inventory was otherwise credited toward the component quantities.

## Reviewed substitutions

These are procurement alternatives for the existing footprints and circuits;
the accepted native PCB files and fabrication outputs were not changed.

| Original | Selected in cart | Compatibility |
| --- | --- | --- |
| C3216X7R1E106K160AB | CL31B106KLHNNNE | 10 µF X7R 1206, 35 V instead of 25 V; sensor bias screening checked |
| ERJ3EKF3300V | CRCW0603330RFKEA | 330 Ω, 1%, 0603; 0.125 W instead of 0.1 W; same temperature coefficient |
| GRM32ER71E226ME15L | CGA6P3X7R1E226M250AB | 22 µF, 25 V, X7R, 1210; better typical bias retention, maximum height +0.1 mm |
| PR02FS0201000KA100 | PR02FS0201000KR500 | Same fusible resistor; supply packaging only |
| WP710A10LGD | HLMP-1790 | Low-current green 3 mm LED, nominal 2.54 mm pitch; observe cathode marking |
| SXH-001T-P0.6 | BXH-001T-P0.6 | Same JST contact in loose form |
| 6009.1315 | 11-00017 | NEMA 5-15P to C13, 18 AWG SJT, 10 A 125 VAC, UL/cUL; 2.0 m instead of 2.5 m |

Manufacturer characterization supports the capacitor selections; it does not
replace commissioning measurements. The 10 µF substitution's combined design
screen yields 4.8195 µF at the sensor's maximum supply, above the 4.7 µF target.
Use the specified effective support dimensions when assembling stock fasteners;
account for actual washer thickness and match countersinks to the screw heads.

## Files and evidence

- [Cart lines](cart-lines.csv): selected parts, quantities, live CAD prices and board references.
- [Bulk Add CSV](digikey-bulk-add.csv): no header; quantity, DigiKey SKU, customer reference. Use only in an empty cart to avoid duplicates.
- [Receipt](cart-receipt.json): complete reconciliation against all 103 source purchase lines, source BOM hash and verification record.
- [Passive review](passive-research.json), [active review](active-research.json), [offboard research](offboard-research.json), [hardware research](hardware-research.json), and [cord substitution](cord-substitution.json): source links and compatibility evidence.

Research files retain preliminary stock observations and candidate quantities.
They are not the order list. The final receipt and cart override them: several
cached stock pages disagreed with the live cart, including the inlet cover,
fuse and terminal blocks. The final cart includes the exact RC320-01 cover
(Schurter 3-125-661), which the live cart confirmed available.

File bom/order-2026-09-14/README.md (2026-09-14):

# Purchase list for one Crystal Shim

One controller, one mains board and one tank sensor require **135 physical PCB
components in 50 exact MPN groups**: controller 99, mains 22, sensor 14. All 159
native footprint references and MPN fields match the accepted handoff manifests;
24 footprints are board features with no purchased component. Every PCB part
quantity matches the active rows of `bom/bom.csv`.

This order uses bare PCBs and owner assembly. All current controller components,
including the three future pump drivers and reservoir interface, are populated.
Future pumps, reservoir sensor board and accessory harnesses are not included.
Bare-board quantities, Gerbers and stencils belong to the fabrication release.
There is no JLCPCB assembly BOM/CPL upload or paid impedance-control requirement
in this purchasing list.

## Files

- [order-bom.json](order-bom.json): typed machine-readable purchasing data with
  explicit board allocations, status, quantities, sources and supplier searches.

- [consolidated-purchase.csv](consolidated-purchase.csv): shopping list with exact
  duplicate MPNs combined across boards and offboard uses. Required quantities,
  optional spares and suggested purchases are separate columns. Generic mounting
  stock appears alongside the fixed components; consult its detail below.
- [pcb-parts.csv](pcb-parts.csv): 50 grouped PCB MPNs, with board-specific references.
- [pcb-reference-list.csv](pcb-reference-list.csv): one row per physical component.
- [offboard-parts.csv](offboard-parts.csv): harness, enclosure, service kit and
  mounting stock, including explicit selection/fit limitations.
- [excluded-pcb-features.csv](excluded-pcb-features.csv): controller H1–H4/TP1–TP14,
  mains H1–H4 and sensor E1/J1. Do not order these identifiers as components.
- [reconciliation.json](reconciliation.json): counts and input SHA-256 receipts.

Quantities are for **one complete set**, independent of a fabricator's minimum
bare-board batch. Optional PCB spares are generally three or 20% for resistor and
capacitor groups, one small semiconductor/connector, and zero for the large PSU,
relay, MOV and mains terminals. These are handling/rework allowances, not a second
complete build. Adjust distributor pack quantities at checkout. No price, stock
availability, tax or shipping claim is made. Supplier lookup URLs are exact-MPN
searches, not confirmed inventory listings.

Purchase status is copied from the canonical BOM. No Stillair stock is allocated.
The GST18U05-P1J adapter is described as already known in the source notes but has
no purchase receipt: verify it is owned before buying. The list reserves one and
suggests zero purchases until that check; buy one if it is unavailable.

## Offboard selections and allowances

The ordinary stock choices below close purchasing ambiguity without claiming
measured assembly performance:

- **Sensor cable:** Alpha Wire 5493C, slate, three twisted 24 AWG pairs. Buy a
  1 m cut length; the **complete installed harness remains at most 203.2 mm**.
  Manufacturer values give about 16.27 pF pair capacitance and 29.33 pF ground
  capacitance at that limit. The catalog bend radius is ten cable diameters, so
  confirm reach and entry geometry without forcing a tight bend. Keep the foil
  and drain insulated at both ends; neither connects to the driven shields.
  [Alpha construction and electrical data](https://www.alphawire.com/products/cable/xtra-guard-performance-cable/xtra-guard-1/5493c).
- **Sensor adhesive:** genuine 3M 467MP transfer film, with no foam. Buy enough
  small sheet/strip stock for three 18 × 64 mm patches. Manufacturer pages give
  0.05 mm and the current technical sheet gives 0.06 mm; record the received film
  and installed gap during calibration. Glass/soldermask retention and wet-area
  durability remain unmeasured.
  [3M technical sheet](https://multimedia.3m.com/mws/media/2522781O/3m-adhesive-transfer-tape-467mp.pdf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).
- **Wire:** provision 2 m each of 18 AWG 6715 black/white for mains, 2 m of 18 AWG
  3075 green/yellow for PE, 1 m each of 22 AWG 6713 red/black/blue for the 5 V/coil
  and service harnesses, and 1 m each of 20 AWG 6714 red/black for the internal
  12 V link. These are cutting-stock allowances, not approved final harness
  lengths. Buy cut lengths where possible instead of industrial spools.
  Current wire-family sources are in the CSV rows.
- **Contacts:** 16 Micro-Fit 43030-0007 fitted contacts, plus eight suggested
  spares. This includes six tank-sensor, six 5 V/coil, and four 12 V terminations.
  The service connector is separate JST XH: XHP-2 and two SXH-001T-P0.6 contacts.
  Canonical BOM-93 now identifies the service cable's JST XH termination. [Molex wire range](https://www.molex.com/en-us/products/part-detail/430300007).
- **Inlet/filter tabs:** eight 2-520184-2 receptacles, plus two spares: three
  inlet L/N/PE tabs and five filter LINE/LOAD/PE tabs. The exact TE 802490-SF
  model confirms a PE FASTON blade on this 1 A filter, not an earth stud. The
  three central junction rings remain separate.
  [Schurter inlet](https://www.schurter.com/en/datasheet/typ_6200.pdf),
  [exact TE filter model and datasheet](https://www.te.com/en/product-802490-SF.html).
- **Output gland:** retain M3231 and add black nylon locknut 8463. The gland has
  an integral sealing ring, so no additional O-ring is specified. Check thread
  engagement against the actual enclosure wall and cord jacket before machining.
  [Heyco catalog](https://www.heyco.com/Brochures/Solar_broch.pdf).

## Mechanical stock package

The purchase list now follows the [mechanical closure](../../docs/design/evidence/pre-fab-2026-09-14/mechanical-closure.md).
It replaces the original generic 45 mm standoff kit with an independent frame
that preserves the hole-free separator and accepted board elevations:

- One 250 × 250 × 3 mm unclad FR-4 sheet for the carrier, two H-rails and PE bracket.
- One 200 × 200 × 2 mm unclad FR-4 sheet for the separator and eight corner tabs.
- Four continuous M4 nylon rods at least 80 mm long, frame nuts/washers, six
  base-hole seals in total, four effective 3.2 mm carrier feet and four 10 mm
  external enclosure feet.
- Four plain 7 mm lower and four plain 3 mm upper M3 PCB spacers. Single
  through-bolts avoid opposing screws inside short spacers. Four M3 × 16 mm
  pan-head and twelve M3 × 12 mm countersunk bolts cover PCB and corner-stop joints.
- A separately clamped M4 metal PE junction and insulating cover, with two M4 ×
  30 mm nylon bracket bolts and two effective 8.2 mm bracket feet. The metal
  electrical pressure stack contains no creeping polymer layer.
- Two external glass-side cable-tie bases, nylon ties and 3M VHB 5952 for those
  bases only. Thin 467MP remains the sensor-to-glass adhesive.

Required stock quantities and spares are separate in the CSV/JSON. Purchase FR-4
with a supplier flame-rating receipt at the actual 2 mm/3 mm thickness; generic
unrated G10 is not the same specification. The mechanical document governs final
cutting, hole locations, effective spacer heights and assembly. Generic material
rows intentionally name purchasable dimensions/materials instead of inventing
manufacturer part numbers.

The PCB order is reconciled and the ordinary stock-material construction is
specified. These files do not claim measured tape adhesion, crimp pull strength,
received-material tolerances, enclosure sealing, sensor calibration, temperatures
or electrical commissioning. No parts have been bought and no stock is allocated.

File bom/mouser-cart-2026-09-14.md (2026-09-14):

# Final component cart, Mouser Canada

Historical cart proposal. Purchased as [order 40452969](purchases/40452969/README.md)
with increased quantities; that receipt supersedes quantities and totals below.

Prepared in the owner’s logged-in account on 2026-09-14 and verified after reload.
No checkout or purchase performed. Inventory remains Not ordered until confirmed.
One of each covers the six outstanding inventory lines for one of each board.
PCBs and stencils are ordered separately from JLCPCB.

| MPN | Mouser number | Qty | Extended CAD | Cart availability |
| --- | --- | ---: | ---: | --- |
| AP63203WU-7 | 621-AP63203WU-7 | 1 | 1.28 | Backordered; 22,231 expected September 18, 2026 |
| AP63205WU-7 | 621-AP63205WU-7 | 1 | 1.31 | Ships now |
| G5RL-1A-TV8 DC5 | 653-G5RL-1A-TV8DC5 | 1 | 7.03 | Ships now |
| TMOV14RP175E | 576-TMOV14RP175E | 1 | 2.81 | Ships now |
| TPS2553DBVR | 595-TPS2553DBVR | 1 | 1.58 | Ships now |
| USBLC6-2SC6 | 511-USBLC6-2SC6 | 1 | 0.71 | Ships now |
| M0599-4-N | 761-M0599-4-N | 6 | 12.12 | Ships in 20 days |

Merchandise CA$26.84; displayed UPS Worldwide Express Saver shipping CA$20;
subtotal CA$46.84 before tax. Shipping and backorder shipment choices remain
for owner checkout. Expected replenishment is not a guaranteed delivery date.
Small ICs use cut tape, without MouseReel charges. The MOV is the approved bulk
part for the updated footprint. Cart contains seven lines. Owner subsequently requested six nylon spacer blanks:
four to trim to 3.2 mm and two to trim to 8.2 mm. Added and verified at CA$2.02
each; these are additional purchases despite the earlier existing-stock declaration.
No inventory credit or purchase status change until checkout is confirmed.

[Open the account cart](https://www.mouser.ca/en/Cart/).

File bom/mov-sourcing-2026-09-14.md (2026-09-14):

# MOV sourcing and alternative fit

Historical pre-ECO review, 2026-09-14. No MOV was ordered. The owner subsequently
authorized a footprint change for TMOV14RP175E; the current
[capture contract](../docs/design/mov-capture.md) supersedes the old-footprint fit
assessment below.

## Exact part

No confirmed quantity-one source for TMOV14RP175EL2T7 was found.

- [Mouser Canada](https://www.mouser.ca/en/ProductDetail/Littelfuse/TMOV14RP175EL2T7?qs=PalBzRKzfntz9V2gxzK2yg%3D%3D): native browser catalog showed non-stocked, 16 weeks, minimum 1500, multiple 500.
- [Newark Canada](https://canada.newark.com/littelfuse/tmov14rp175el2t7/thermally-protected-varistor-14mm/dp/01P8102): full-reel minimum 1500, available to order rather than verified shelf stock.
- [DIRECT](https://www.direct.fr/radial/2976-a.html): indexed listing specifies a 500-piece lot and contact-only ordering; not a verified small-quantity offer.
- DigiKey and LCSC listings showed no exact-part stock. No stocked offer was established through Arrow, Avnet, RS or TME searches; absence from search is not proof they cannot source it.
- [OMO](https://www.omo-ic.com/chip/366/tmov14rp175el2t7-littelfuse.html): quote-only generic availability alongside zero-stock distributor feeds. Quantity-one fulfillment and traceability are unverified. No inquiry sent.
- No purchasable L2B7 packaging-only equivalent was established.

## Stocked alternative

[Mouser Canada TMOV14RP175E](https://www.mouser.ca/en/ProductDetail/Littelfuse/TMOV14RP175E?qs=nXjUL3qLHyWPDWqKl1H7NA%3D%3D), SKU 576-TMOV14RP175E: native browser showed 2 in stock, minimum 1, CAD 2.81 each. This is page evidence, not a cart reservation.

Electrical function and ratings match the selected family member; the lead form changes. The [manufacturer family datasheet](https://www.littelfuse.com/assetdocs/tmov-itmov?assetguid=bd475732-1071-4352-b8aa-f78b0007eb05) and [existing footprint/assembly contract](../docs/design/mov-capture.md) give:

- Existing 1.3 mm round hole and 3.7 x 1.3 mm slot, 7.5 mm centre spacing.
- Bulk lead diameter 0.76..0.86 mm; lead spacing components 6.5..8.5 mm and 1.5..4.0 mm.
- Unformed lead-pair span 6.671..9.394 mm. Worst-tolerance footprint capacity, including 0.10 mm differential position error, is 8.940 mm. Worst-case shortfall is 0.454 mm.
- Required yaw can reach 31.61 degrees, exceeding the existing 20-degree assembly limit. Some individual bulk parts can fit unchanged, but the published range does not guarantee it.
- Reducing transverse stagger to at most 2 mm would restore the accepted geometric fit calculation: span at most 8.732 mm, yaw at most 17.10 degrees and 0.208 mm margin. At the worst transverse stagger this is approximately 1 mm movement per lead if shared symmetrically.

That geometric calculation does not qualify a forming process. No applicable manufacturer bend-radius/body-setback procedure was found for this thermally protected device. Published dimensions also do not guarantee the complete installed body location. A particular bulk part can be accepted without a footprint change only after stress-free unpowered fit within the existing 27 x 27 mm occupied envelope, 26 mm height and insulation limits is established. No forming recipe or substitution is approved by this note.

The bulk part is a conditional procurement fallback, not a guaranteed drop-in. A footprint change remains a possible next decision if guaranteed full-tolerance compatibility is required. The owner asked to consider that only after exact sourcing and alternative-fit review; this review does not authorize or perform a footprint change.

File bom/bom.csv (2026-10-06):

ID | Assembly | Manufacturer | Part number | Qty | Function | Design status | Purchase status | Order ref | Source | Notes
BOM-01 | Sensor | Texas Instruments | FDC1004DGSR | 1 | Capacitance converter | Selected for capture | In stock | DigiKey 101602605 | https://www.ti.com/lit/ds/symlink/fdc1004.pdf | Sensor: U1; exact current source population; see board design basis and footprint audit. Native/fabrication release remains separate. Purchased 1 x FDC1004DGSR (296-48544-1-ND); received. Actual order record: bom/purchases/101602605/order.json. Owner confirmation in procurement reconciliation request, 2026-09-30 America/Vancouver.
BOM-02 | Controller | Espressif | ESP32-C6-WROOM-1-N8 | 1 | Wireless MCU module | Selected for capture | In stock | DigiKey 101602605 | https://www.espressif.com/sites/default/files/documentation/esp32-c6-wroom-1_wroom-1u_datasheet_en.pdf | Controller: U1; exact current source population; see board design basis and footprint audit. Native/fabrication release remains separate. Purchased 1 x ESP32-C6-WROOM-1-N8 (1965-ESP32-C6-WROOM-1-N8CT-ND); received. Actual order record: bom/purchases/101602605/order.json. Owner confirmation in procurement reconciliation request, 2026-09-30 America/Vancouver.
BOM-03 | Mains | Mean Well | IRM-45-12 | 1 | Isolated 12 V common power module | Selected for capture | In stock | DigiKey 101602605 | https://www.meanwell.com/Upload/PDF/IRM-45/IRM-45-SPEC.pdf | Mains: U1; exact current source population; see board design basis and footprint audit. Native/fabrication release remains separate. Purchased 1 x IRM-45-12 (1866-3053-ND); received. Actual order record: bom/purchases/101602605/order.json. Owner confirmation in procurement reconciliation request, 2026-09-30 America/Vancouver.
BOM-04 | Mains | Omron | G5RL-1A-TV8 DC5 | 1 | Normally-open pump relay | Selected for capture | In stock | Mouser 40452969 | https://components.omron.com/us-en/products/relays/G5RL | Mains: K1; exact current source population; see board design basis and footprint audit. Native/fabrication release remains separate. Purchased 1 x G5RL-1A-TV8 DC5 (653-G5RL-1A-TV8DC5); original 2026-09-14 receipt availability: 1 Ships Now. Received. Actual order record: bom/purchases/40452969/order.json. Shipped 2026-10-02 on invoice 92822100 after the spacer line was cancelled; owner receipt report, 2026-10-05 America/Vancouver.
BOM-05 | Enclosure mains | TE/Schaffner | FN2090A-1-06 / 802490-SF | 1 | Manufactured two-stage EMI filter | Capture candidate | In stock | DigiKey 101602605 | https://www.te.com/en/product-CAT-P97-F2090.html | 1 A low-leakage two-stage filter on pump branch; attenuation/install tests owed Purchased 1 x FN2090A-1-06 (817-2400-ND); received. Actual order record: bom/purchases/101602605/order.json. Owner confirmation in procurement reconciliation request, 2026-09-30 America/Vancouver.
BOM-06 | Sensor harness | Molex | 43025-0600 | 1 | Six-position cable receptacle housing | Capture candidate | In stock | DigiKey 101602605 | https://www.molex.com/en-us/products/part-detail/430250600 | One controller-end housing; sensor end solders to J1 pigtail pads; mates 43045-0600 with six 43030-0007 tin contacts Purchased 10 x 0430250600 (WM1785-ND); received. Actual order record: bom/purchases/101602605/order.json. Owner confirmation in procurement reconciliation request, 2026-09-30 America/Vancouver.
BOM-07 | Controller | Molex | 43045-0600 | 2 | Tank and reservoir sensor headers | Selected for capture | In stock | DigiKey 101602605 | https://www.molex.com/en-us/products/part-detail/430450600 | Controller J5 and J3. Sensor J1 is a board-only solder-pad interface, excluded from purchased components. Purchased 2 x 0430450600 (WM1815-ND); received. Actual order record: bom/purchases/101602605/order.json. Owner confirmation in procurement reconciliation request, 2026-09-30 America/Vancouver.
BOM-08 | Sensor harness | Molex | 43030-0007 | 6 | Female crimp contact | Capture candidate | In stock | DigiKey 101602605 | https://www.molex.com/en-us/products/part-detail/430300007 | Loose tin female 20-24 AWG; use 24 AWG sensor cable; no Stillair stock allocated Purchased 25 x 0430300007 (WM1837-ND); received. Actual order record: bom/purchases/101602605/order.json. Owner confirmation in procurement reconciliation request, 2026-09-30 America/Vancouver.
BOM-09 | Mains | Phoenix Contact | 1868076 | 4 | Two-position fixed side-entry mains screw terminals | Selected for capture | In stock | DigiKey 101602605 | https://www.phoenixcontact.com/en-us/products/pcb-terminal-block-mkds-5-2-762-1868076 | Mains J1-J4; MKDS 5/2-7,62; both positions used L1/N2; no housing or crimp contacts; see terminal capture basis for assembly limits. Purchased 4 x 1868076 (277-5840-ND); received. Actual order record: bom/purchases/101602605/order.json. Owner confirmation in procurement reconciliation request, 2026-09-30 America/Vancouver.
BOM-10 | Enclosure | Schurter | 6200.2300 | 1 | Standard mains input | Capture candidate | In stock | DigiKey 101602605 | https://www.schurter.com/en/datasheet/typ_6200.pdf | C14 with one wired 5x20 fuse pole; RC320 terminal cover separate Purchased 1 x 6200.23 (486-1032-ND); received. Actual order record: bom/purchases/101602605/order.json. Owner confirmation in procurement reconciliation request, 2026-09-30 America/Vancouver.
BOM-11 | Enclosure | Americord | 1112.048.005350 | 1 | Mains receptacle or female pigtail | Capture candidate | In stock |  | https://www.americord.com/en-ca/products/4ft-roj-2-strip-3-8-to-nema-5-15r-power-cord-18-3-sjtow-na | 4 ft 18/3 SJTOW; 10 A/125 V; confirm received jacket OD and gland fit Owner confirms sufficient existing stock for this build; no purchase or shipment tracked.
BOM-12 | Mains | Littelfuse | 0215002.MXP | 1 | 2 A time-lag inlet fuse F1 | Selected for capture | In stock | DigiKey 101602605 | https://www.littelfuse.com/assetdocs/fuse-215-datasheet?assetguid=990f7193-d9a2-48e4-b760-2b43514249cf | 215-series ceramic 5x20 cartridge in 6200.2300 inlet. 190 mV maximum drop at rated current. Final assembly cold starts remain untested. Purchased 2 x 0215002.MXP (F4609-ND); received. Actual order record: bom/purchases/101602605/order.json. Owner confirmation in procurement reconciliation request, 2026-09-30 America/Vancouver.
BOM-13 | Mains | Littelfuse | TMOV14RP175E | 1 | Protected MOV surge network | Selected for capture | In stock | Mouser 40452969 | https://www.littelfuse.com/assetdocs/tmov-itmov?assetguid=bd475732-1071-4352-b8aa-f78b0007eb05 | Mains: RV1; exact current source population; see board design basis and footprint audit. Native/fabrication release remains separate. Purchased 2 x TMOV14RP175E (576-TMOV14RP175E); original 2026-09-14 receipt availability: 2 Ships Now. Received. Actual order record: bom/purchases/40452969/order.json. Shipped 2026-10-02 on invoice 92822100 after the spacer line was cancelled; owner receipt report, 2026-10-05 America/Vancouver.
BOM-14 | Mains | TDK | B32921C3473K000 | 1 | 47 nF X2 capacitor in load RC network | Selected for capture | In stock | DigiKey 101602605 | https://www.tdk-electronics.tdk.com/en/3191402/products/product-catalog/film-capacitors/emi-suppression-capacitors/search-results-deltacap-capacitors | Mains: C1; exact current source population; see board design basis and footprint audit. Native/fabrication release remains separate. Purchased 1 x B32921C3473K000 (495-6903-ND); received. Actual order record: bom/purchases/101602605/order.json. Owner confirmation in procurement reconciliation request, 2026-09-30 America/Vancouver.
BOM-15 | Controller | Alpha & Omega Semiconductor | AO3400A | 4 | Relay and future motor low-side switches | Selected for capture | In stock | DigiKey 101602605 | https://www.aosmd.com/res/data_sheets/AO3400A.pdf | Controller: Q2, Q3, Q4, Q1; exact current source population; see board design basis and footprint audit. Native/fabrication release remains separate. Purchased 10 x AO3400A (785-1000-1-ND); received. Actual order record: bom/purchases/101602605/order.json. Owner confirmation in procurement reconciliation request, 2026-09-30 America/Vancouver.
BOM-16 | Controller | Diodes Incorporated | AP63203WU-7 | 1 | Controller fixed 3.3 V buck | Selected for capture | In stock | Mouser 40452969 | https://www.diodes.com/datasheet/download/AP63200-AP63201-AP63203-AP63205.pdf | Controller: U2; exact current source population; see board design basis and footprint audit. Native/fabrication release remains separate. Purchased 2 x AP63203WU-7 (621-AP63203WU-7); original 2026-09-14 receipt availability: 2 Backordered. Received. Actual order record: bom/purchases/40452969/order.json. Shipped 2026-10-02 on invoice 92822100 after the spacer line was cancelled; owner receipt report, 2026-10-05 America/Vancouver.
BOM-17 | Sensor | Texas Instruments | TPS7A2433DBVR | 1 | Fixed 3.3 V sensor regulator | Selected for capture | In stock | DigiKey 101602605 | https://www.ti.com/lit/ds/symlink/tps7a24.pdf | Sensor: U2; exact current source population; see board design basis and footprint audit. Native/fabrication release remains separate. Purchased 1 x TPS7A2433DBVR (296-TPS7A2433DBVRCT-ND); received. Actual order record: bom/purchases/101602605/order.json. Owner confirmation in procurement reconciliation request, 2026-09-30 America/Vancouver.
BOM-18 | Controller | GCT | USB4105-GF-A | 1 | Self-powered USB-C data/service connector | Selected for capture | In stock | DigiKey 101602605 | https://gct.co/files/drawings/usb4105.pdf | Controller: J4; exact current source population; see board design basis and footprint audit. Native/fabrication release remains separate. Purchased 10 x USB4105-GF-A (2073-USB4105-GF-ACT-ND); received. Actual order record: bom/purchases/101602605/order.json. Owner confirmation in procurement reconciliation request, 2026-09-30 America/Vancouver.
BOM-19 | Controller | Kingbright | WP710A10LGD | 1 | Green status LED | Selected for capture | In stock | DigiKey 101602605 | https://www.kingbrightusa.com/images/catalog/SPEC/WP710A10LGD.pdf | Controller: D4; exact current source population; see board design basis and footprint audit. Native/fabrication release remains separate. Purchased 2 x HLMP-1790 (516-1310-ND); received. Actual order record: bom/purchases/101602605/order.json. Owner confirmation in procurement reconciliation request, 2026-09-30 America/Vancouver.
BOM-20 | Controller | Omron | B3F-1002-G | 3 | Maintenance / BOOT / reset buttons | Selected for capture | In stock | DigiKey 101602605 | https://components.omron.com/us-en/system/files/2023-01/datasheet_pdf/A070-E1.pdf | Controller: SW1, SW2, SW3; exact current source population; see board design basis and footprint audit. Native/fabrication release remains separate. Purchased 3 x B3F-1002-G (SW787-ND); received. Actual order record: bom/purchases/101602605/order.json. Owner confirmation in procurement reconciliation request, 2026-09-30 America/Vancouver.
BOM-21 | Enclosure | Hammond | 1590ZGRP243 | 1 | Flame-rated splash-resistant enclosure | Capture candidate | In stock |  | https://www.hammfg.com/part/1590ZGRP243 | 400x250x120 mm nominal GRP UL94 V-0 IP66 enclosure; insulating partition and simple standoffs; current manufacturer STEP fit receipt in cad/shared-enclosure. Modified cutouts do not inherit catalog rating. Inventory status set by owner.
BOM-22 | Sensor mount | 3M | 467MP | 1 | Thin uniform adhesive film for sensor-to-glass mounting | Selected for owner assembly | In stock | DigiKey 101602605 | https://multimedia.3m.com/mws/media/2522781O/3m-adhesive-transfer-tape-467mp.pdf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 | One18x64mm patch of thin transfer film; no foam. Purchase three-patch stock allowance separately. Published thickness0.05–0.06mm; actual installed thickness and adhesion become calibration/commissioning inputs. Purchased 1 x 467MP-1-5 (1067-467MP-1-5-ND); received. Actual order record: bom/purchases/101602605/order.json. Owner confirmation in procurement reconciliation request, 2026-09-30 America/Vancouver.
BOM-23 | Sensor harness | Alpha Wire | 5493C | 1 | Three-pair cable at most 8 inches | Selected for owner assembly | In stock | AliExpress; order number not provided | https://www.alphawire.com/products/cable/xtra-guard-performance-cable/xtra-guard-1/5493c | Slate three-pair24AWG cable. One complete harness<=203.2mm, including internal reach and terminations. Alpha design reference uses 1 m cutting stock; received AliExpress purchase length remains unknown, no new purchase requested. Pairs1–4 power,2–5 SDA,3–6 SCL. Cut back and insulate overall foil/drain at both ends; no driven-shield connection. Received reach/bend/strain relief and rise time remain physical checks. Owner confirmed twisted-pair cable ordered from AliExpress on 2026-09-14; actual manufacturer/model, purchased length, gauge and pair count not recorded. This does not confirm purchase of Alpha 5493C or approve equivalence. Received: Owner confirmation in procurement reconciliation request, 2026-09-30 America/Vancouver. Purchased cable specs/length unknown; external sensor harness build remains unconfirmed.
BOM-24 | Mains | Vishay | PR02FS0201000KA100 | 1 | 100 ohm 2W snubber resistor | Selected for capture | In stock | DigiKey 101602605 | https://www.vishay.com/docs/28915/pr02fs.pdf | Mains: R1; exact current source population; see board design basis and footprint audit. Native/fabrication release remains separate. Purchased 1 x PR02FS0201000KR500 (BC3366CT-ND); received. Actual order record: bom/purchases/101602605/order.json. Owner confirmation in procurement reconciliation request, 2026-09-30 America/Vancouver.
BOM-25 | Mains | Vishay | 1N4007-E3/54 | 1 | Relay flyback diode | Selected for capture | In stock | DigiKey 101602605 | https://www.vishay.com/docs/88503/1n4001.pdf | Mains: D1; exact current source population; see board design basis and footprint audit. Native/fabrication release remains separate. Purchased 1 x 1N4007-E3/54 (1N4007-E3/54GICT-ND); received. Actual order record: bom/purchases/101602605/order.json. Owner confirmation in procurement reconciliation request, 2026-09-30 America/Vancouver.
BOM-26 | Controller/Mains | Bourns | SRP5030TA-4R7M | 2 | 4.7 uH buck inductors | Selected for capture | In stock | DigiKey 101602605 | https://www.bourns.com/docs/product-datasheets/srp5030ta.pdf | Controller: L1; Mains: L1; exact current source population; see board design basis and footprint audit. Native/fabrication release remains separate. Purchased 2 x SRP5030TA-4R7M (SRP5030TA-4R7MCT-ND); received. Actual order record: bom/purchases/101602605/order.json. Owner confirmation in procurement reconciliation request, 2026-09-30 America/Vancouver.
BOM-27 | Controller/Sensor | STMicroelectronics | STPS2L40U | 6 | Source OR / motor flyback / sensor reverse diodes | Selected for capture | In stock | DigiKey 101602605 | https://www.st.com/resource/en/datasheet/stps2l40.pdf | Controller: D9, D10, D11, D1, D2; Sensor: D2; exact current source population; see board design basis and footprint audit. Native/fabrication release remains separate. Purchased 10 x STPS2L40U (497-5574-1-ND); received. Actual order record: bom/purchases/101602605/order.json. Owner confirmation in procurement reconciliation request, 2026-09-30 America/Vancouver.
BOM-28 | Controller | Texas Instruments | TPS3808G01DBVR | 1 | PSU voltage supervisor | Selected for capture | In stock | DigiKey 101602605 | https://www.ti.com/lit/ds/symlink/tps3808.pdf | Controller: U4; exact current source population; see board design basis and footprint audit. Native/fabrication release remains separate. Purchased 1 x TPS3808G01DBVR (296-17188-1-ND); received. Actual order record: bom/purchases/101602605/order.json. Owner confirmation in procurement reconciliation request, 2026-09-30 America/Vancouver.
BOM-29 | Controller | Texas Instruments | SN74LVC1G08DBVR | 1 | PSU-good AND relay-request gate | Selected for capture | In stock | DigiKey 101602605 | https://www.ti.com/lit/ds/symlink/sn74lvc1g08.pdf | Controller: U6; exact current source population; see board design basis and footprint audit. Native/fabrication release remains separate. Purchased 10 x SN74LVC1G08DBVR (296-11601-1-ND); received. Actual order record: bom/purchases/101602605/order.json. Owner confirmation in procurement reconciliation request, 2026-09-30 America/Vancouver.
BOM-30 | Controller | onsemi | FSUSB42MUX | 1 | USB data isolation switch | Selected for capture | In stock | DigiKey 101602605 | https://www.onsemi.com/download/data-sheet/pdf/fsusb42-d.pdf | Controller: U8; exact current source population; see board design basis and footprint audit. Native/fabrication release remains separate. Purchased 1 x FSUSB42MUX (FSUSB42MUXCT-ND); received. Actual order record: bom/purchases/101602605/order.json. Owner confirmation in procurement reconciliation request, 2026-09-30 America/Vancouver.
BOM-31 | Controller | Texas Instruments | SN74LVC1G14DBVR | 1 | USB VBUS detector/inverter | Selected for capture | In stock | DigiKey 101602605 | https://www.ti.com/lit/ds/symlink/sn74lvc1g14.pdf | Controller: U7; exact current source population; see board design basis and footprint audit. Native/fabrication release remains separate. Purchased 10 x SN74LVC1G14DBVR (296-11607-1-ND); received. Actual order record: bom/purchases/101602605/order.json. Owner confirmation in procurement reconciliation request, 2026-09-30 America/Vancouver.
BOM-32 | Controller | STMicroelectronics | USBLC6-2SC6 | 1 | USB ESD protection | Selected for capture | In stock | Mouser 40452969 | https://www.st.com/resource/en/datasheet/usblc6-2.pdf | Controller: U9; exact current source population; see board design basis and footprint audit. Native/fabrication release remains separate. Purchased 2 x USBLC6-2SC6 (511-USBLC6-2SC6); original 2026-09-14 receipt availability: 2 Ships Now. Received. Actual order record: bom/purchases/40452969/order.json. Shipped 2026-10-02 on invoice 92822100 after the spacer line was cancelled; owner receipt report, 2026-10-05 America/Vancouver.
BOM-33 | Controller | Texas Instruments | TCA9517ADGKR | 2 | Tank and reservoir I2C buffers | Selected for capture | In stock | DigiKey 101602605 | https://www.ti.com/lit/ds/symlink/tca9517a.pdf | Controller: U12, U3; exact current source population; see board design basis and footprint audit. Native/fabrication release remains separate. Purchased 2 x TCA9517ADGKR (296-39220-1-ND); received. Actual order record: bom/purchases/101602605/order.json. Owner confirmation in procurement reconciliation request, 2026-09-30 America/Vancouver.
BOM-34 | Enclosure | Schurter | RC320 | 1 | IEC rear terminal cover | Capture candidate | In stock | DigiKey 101602605 | https://www.schurter.com/en/datasheet/typ_6200.pdf | Matched 6200 inlet accessory Purchased 1 x 3-125-661 (486-3-125-661-ND); received. Actual order record: bom/purchases/101602605/order.json. Owner confirmation in procurement reconciliation request, 2026-09-30 America/Vancouver.
BOM-35 | Controller/Mains | Molex | 43650-0300 | 2 | 5 V / ground / coil harness headers | Selected for capture | In stock | DigiKey 101602605 | https://www.molex.com/en-us/products/part-detail/436500300 | Controller: J1; Mains: J5; exact current source population; see board design basis and footprint audit. Native/fabrication release remains separate. Purchased 2 x 0436500300 (WM1861-ND); received. Actual order record: bom/purchases/101602605/order.json. Owner confirmation in procurement reconciliation request, 2026-09-30 America/Vancouver.
BOM-36 | Controller/mains harness | Molex | 43645-0300 | 2 | Three-position LV cable housing | Capture candidate | In stock | DigiKey 101602605 | https://www.molex.com/en-us/products/part-detail/436450300 | Mates 43650-0300 Purchased 3 x 0436450300 (WM1846-ND); received. Actual order record: bom/purchases/101602605/order.json. Owner confirmation in procurement reconciliation request, 2026-09-30 America/Vancouver.
BOM-37 | Controller/mains harness | Molex | 43030-0007 | 6 | LV harness female contact | Capture candidate | In stock | DigiKey 101602605 | https://www.molex.com/en-us/products/part-detail/430300007 | 22 AWG; six separate terminations Purchased 25 x 0430300007 (WM1837-ND); received. Actual order record: bom/purchases/101602605/order.json. Owner confirmation in procurement reconciliation request, 2026-09-30 America/Vancouver.
BOM-38 | Controller/Mains | Molex | 43045-0200 | 5 | 12 V feed / motor output headers | Selected for capture | In stock | DigiKey 101602605 | https://www.molex.com/en-us/products/part-detail/430450200 | Controller J6-J9; Mains J6. Controller 5 V service J2 uses JST XH. Purchased 5 x 0430450200 (WM1813-ND); received. Actual order record: bom/purchases/101602605/order.json. Owner confirmation in procurement reconciliation request, 2026-09-30 America/Vancouver.
BOM-39 | 12 V harness | Molex | 43025-0200 | 2 | Two-position cable housing | Capture candidate | In stock | DigiKey 101602605 | https://www.molex.com/en-us/products/part-detail/430250200 | Two ends of the internal fused 12 V harness; future pump accessory mates are deferred. Purchased 3 x 0430250200 (WM1783-ND); received. Actual order record: bom/purchases/101602605/order.json. Owner confirmation in procurement reconciliation request, 2026-09-30 America/Vancouver.
BOM-40 | 12 V harness | Molex | 43030-0007 | 4 | Internal 12 V cable contacts | Capture candidate | In stock | DigiKey 101602605 | https://www.molex.com/en-us/products/part-detail/430300007 | 20-24 AWG contacts: four internal 12 V terminations. Splice inline-holder leads to compatible wire. Purchased 25 x 0430300007 (WM1837-ND); received. Actual order record: bom/purchases/101602605/order.json. Owner confirmation in procurement reconciliation request, 2026-09-30 America/Vancouver.
BOM-54 | Mains harness | Alpha Wire | 6715 |  | Internal black and white mains wire | Capture candidate | In stock |  | https://www.alphawire.com/en/products/wire/ecogen/ecowire/6715 | 18 AWG 600 V 105 C; OD 1.70 +/-0.05 mm; lengths and colour order suffixes pending Owner confirms sufficient existing stock for this build; exact manufacturer part number and total stock count not recorded.
BOM-55 | PE harness | Alpha Wire | 3075 |  | Green/yellow PE wire | Capture candidate | In stock |  | https://www.alphawire.com/en/products/wire/hook-up-wire/premium/3075 | 18 AWG 600 V 105 C; OD 2.82 +/-0.10 mm; lengths and colour order suffix pending Owner confirms sufficient existing stock for this build; exact manufacturer part number and total stock count not recorded.
BOM-56 | Controller/mains harness | Alpha Wire | 6713 |  | Red black and blue LV harness wire | Capture candidate | In stock |  | https://www.alphawire.com/en/products/wire/ecogen/ecowire/6713 | 22 AWG 600 V 105 C; verify exact order suffixes and cut lengths in harness drawing Owner confirms sufficient existing stock for this build; exact manufacturer part number and total stock count not recorded.
BOM-57 | Mains harness | TE Connectivity | 2-520184-2 | 8 | Insulated 6.35 mm receptacle | Capture candidate | In stock | DigiKey 101602605 | https://www.te.com/en/product-2-520184-2.html | Eight fitted: inlet L/N/PE (3), filter LINE/LOAD L/N (4), filter PE (1). Exact TE 802490-SF model confirms the fifth filter terminal is a PE FASTON blade. Three central PE rings are separate. Buy ten including two spare. Purchased 10 x 2-520184-2 (A27817-ND); received. Actual order record: bom/purchases/101602605/order.json. Owner confirmation in procurement reconciliation request, 2026-09-30 America/Vancouver.
BOM-58 | PE harness | TE Connectivity | 31886 | 2 | Inlet and filter PE stud ring | Capture candidate | In stock | DigiKey 101602605 | https://www.te.com/en/product-31886.html | #8/M4 PIDG; 22-16 AWG; insulation 2.67-3.56 mm; one per separate PE branch Purchased 2 x 31886 (A27238-ND); received. Actual order record: bom/purchases/101602605/order.json. Owner confirmation in procurement reconciliation request, 2026-09-30 America/Vancouver.
BOM-59 | PE harness | TE Connectivity | 320551 | 1 | Pigtail PE stud ring | Capture candidate | In stock | DigiKey 101602605 | https://www.te.com/en/product-320551.html | #8/M4 PIDG; 22-16 AWG; insulation 2.03-3.18 mm; verify received pigtail conductor Purchased 1 x 320551 (A27237-ND); received. Actual order record: bom/purchases/101602605/order.json. Owner confirmation in procurement reconciliation request, 2026-09-30 America/Vancouver.
BOM-60 | Enclosure | Heyco | M3231 | 1 | Output cord gland | Capture candidate | In stock | DigiKey 101602605 | https://www.heyco.com/wp-content/uploads/2024/10/Liquid-Tight-Cordgrips-NPT.pdf | 1/2 NPT; 4.3-11.4 mm cable; 22.2 mm clearance hole; required mounting accessories pending Purchased 1 x M3231 (3720-M3231-ND); received. Actual order record: bom/purchases/101602605/order.json. Owner confirmation in procurement reconciliation request, 2026-09-30 America/Vancouver.
BOM-61 | Enclosure | Schurter | 6009.1315 | 1 | Detachable mains input cord | Capture candidate | In stock |  | https://www.schurter.com/en/datasheet/6009.1315 | 2.5 m 18 AWG SJT; NEMA5-15P to C13; 10 A 125 V Owner confirms an existing mains input cord in stock; manufacturer part number not recorded.
BOM-62 | Controller | Texas Instruments | TPS2553DBVR | 1 | Controlled sensor power feed | Selected for capture | In stock | Mouser 40452969 | https://www.ti.com/lit/ds/symlink/tps2553.pdf | Controller: U5; exact current source population; see board design basis and footprint audit. Native/fabrication release remains separate. Purchased 2 x TPS2553DBVR (595-TPS2553DBVR); original 2026-09-14 receipt availability: 2 Ships Now. Received. Actual order record: bom/purchases/40452969/order.json. Shipped 2026-10-02 on invoice 92822100 after the spacer line was cancelled; owner receipt report, 2026-10-05 America/Vancouver.
BOM-63 | Controller/Mains | Murata | GRM32ER71E226ME15L | 10 | 22 uF 25 V X7R bulk capacitors | Selected for capture | In stock | DigiKey 101602605 | https://ds.murata.com/simsurfing/mlcc.html?partnumbers=%5B%22GRM32ER71E226ME15%22%5D | Controller: C47, C1, C2, C3, C4, C5; Mains: C2, C3, C4, C6; exact current source population; see board design basis and footprint audit. Native/fabrication release remains separate. Purchased 10 x CGA6P3X7R1E226M250AB (445-180363-1-ND); received. Actual order record: bom/purchases/101602605/order.json. Owner confirmation in procurement reconciliation request, 2026-09-30 America/Vancouver.
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

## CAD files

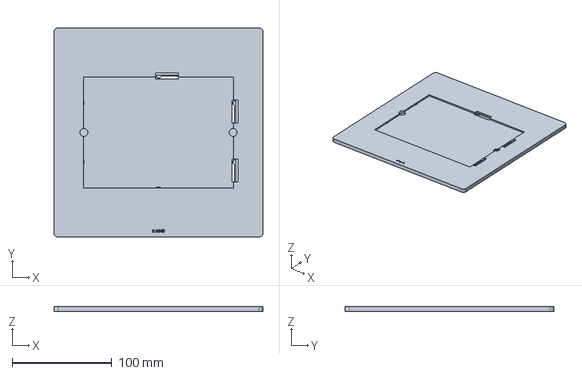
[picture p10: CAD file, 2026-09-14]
cad/stencil-fixtures/output/mains-tray.step
210.0 x 210.0 x 4.80 mm

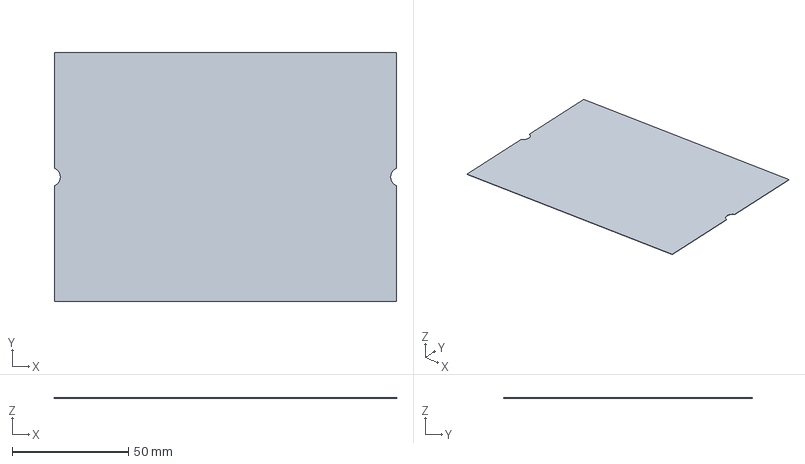
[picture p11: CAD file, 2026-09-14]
cad/stencil-fixtures/output/mains-shim-0.2mm.step
147.0 x 107.0 x 0.2 mm

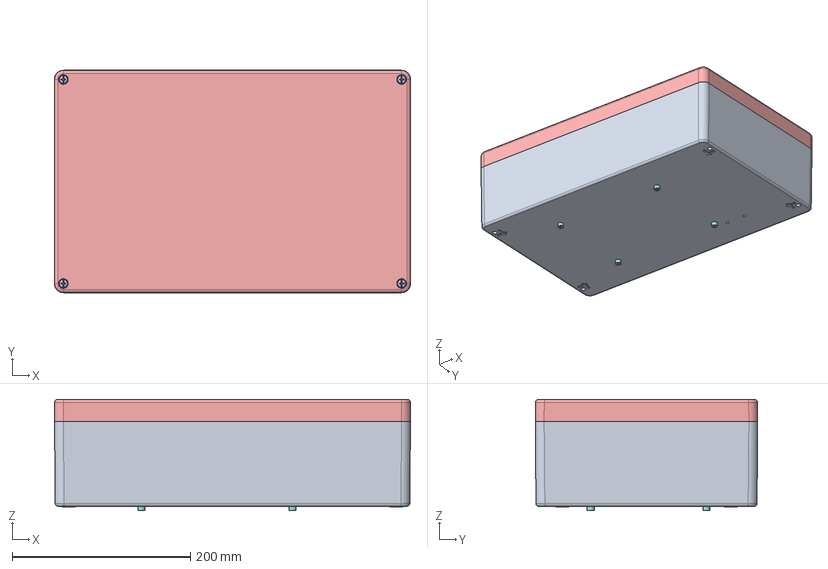
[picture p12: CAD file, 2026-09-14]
cad/shared-enclosure/support-fit.step
400.0 x 250.0 x 125.2 mm

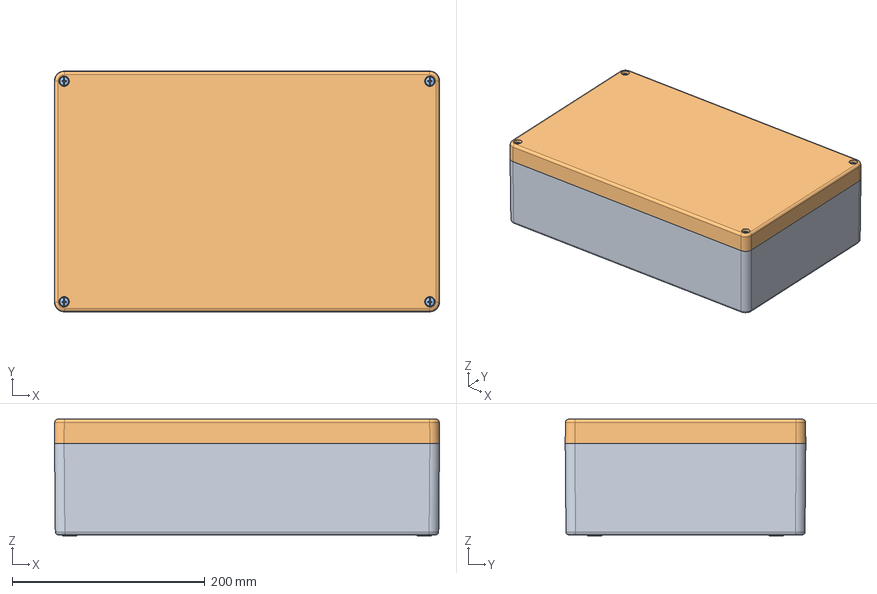
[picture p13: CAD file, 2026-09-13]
cad/shared-enclosure/fit-screen.step
400.0 x 250.0 x 121.3 mm

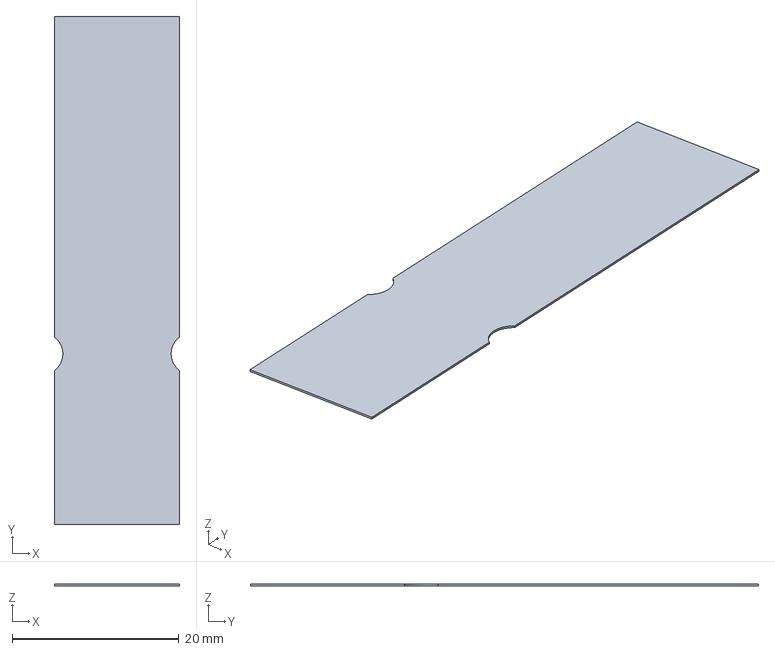
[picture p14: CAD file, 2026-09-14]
cad/stencil-fixtures/output/sensor-shim-0.2mm.step
15.0 x 61.0 x 0.2 mm

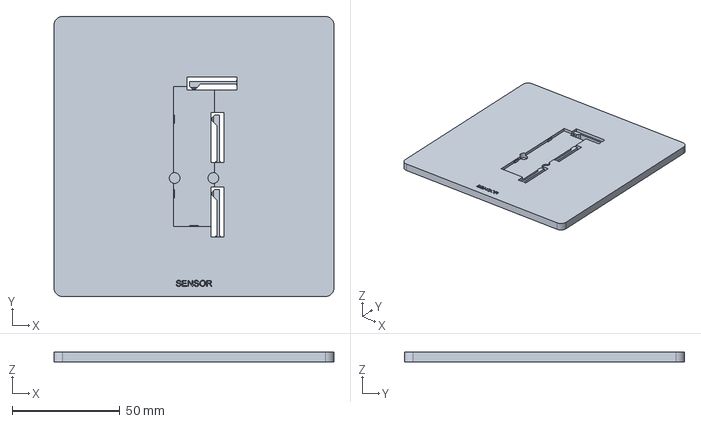
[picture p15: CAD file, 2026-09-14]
cad/stencil-fixtures/output/sensor-tray.step
130.0 x 130.0 x 4.80 mm

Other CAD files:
cad/stencil-fixtures/output/controller-tray.step
cad/stencil-fixtures/output/controller-shim-0.2mm.step
cad/stencil-fixtures/output/controller-shim-0.2mm.3mf
cad/stencil-fixtures/output/controller-shim-0.2mm.stl
cad/stencil-fixtures/output/controller-tray.3mf
cad/stencil-fixtures/output/controller-tray.stl
cad/stencil-fixtures/output/mains-shim-0.2mm.3mf
cad/stencil-fixtures/output/mains-shim-0.2mm.stl
cad/stencil-fixtures/output/mains-tray.3mf
cad/stencil-fixtures/output/mains-tray.stl
cad/stencil-fixtures/output/sensor-shim-0.2mm.3mf
cad/stencil-fixtures/output/sensor-shim-0.2mm.stl
cad/stencil-fixtures/output/sensor-tray.3mf
cad/stencil-fixtures/output/sensor-tray.stl

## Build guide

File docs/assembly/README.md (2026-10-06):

# Assembly bench guide

[Open the printable booklet](crystal-shim-assembly-bench-guide.pdf).

Seventeen Letter pages for one sensor, one controller and one mains board.
Print one copy, duplex with long-edge binding, at normal page size. The last
sheet has a blank back. The booklet covers soldering and internal combination;
firmware, commissioning and tank mounting stay in the interactive build sessions.

## Contents

| Pages | Bench task |
| --- | --- |
| 1–2 | Stencil/hot-bed sequence and SMT package identification |
| 3 | Sensor: all 14 component placements |
| 4–10 | Controller: 12 iron parts and 87 SMT placements, including USB |
| 11–14 | Mains: nine SMT and 13 iron placements; hand-solder details |
| 15 | Sensor pigtail and both internal power/relay harnesses |
| 16 | Inlet, EMI filter, pump pigtail and protective earth |
| 17 | Combining the boards around the intact separator |

## Sources and review

The maps use read-only KiCad pad coordinates and F.Fab outlines from the ordered
native boards. They are component-side views and are not mirrored. Black dots
identify native pad 1 for ICs/MOSFETs and the cathode for diodes/LEDs. Grey
neighbours give positional context. Map scale varies and is not a manufacturing
template.

[parts.json](source/parts.json) reconciles all 135 placements to the actual
[inventory](../../bom/inventory.csv), [DigiKey receipt](../../bom/purchases/101602605/README.md)
and [Mouser receipt](../../bom/purchases/40452969/README.md). It includes approved
capacitor, LED, resistor and packaging substitutions. The 63 board-specific
groups contain 50 distinct purchased MPNs. All circuits are populated; controller
mounting/probe pads and the sensor's built-in copper are not purchased parts.

Four illustrations were generated with the built-in ImageGen tool. The
[prompts and correction prompts](source/imagegen-prompts.json) are retained.
These illustrations show technique and generic package appearance, not verified
lot markings or physical pin-layout drawings. Purchased labels, the exact tables
and native placement maps take precedence. The flipped soldering view was
corrected, and the relay artwork was revised after its four native pins were
confirmed. Some far-side leads are occluded in the generic perspective drawings.

The parts/orientation review and the harness/stack review were independent.
All 17 rendered pages were visually inspected; cropped maps, crowded footers and
stack leaders were corrected. The builder checks all 135 references in both maps
and tables, every purchased MPN in extracted PDF text, native file hashes and
layout overflow. [Build receipt](source/build-receipt.json) identifies the PDF.
The native KiCad files were unchanged. This is document verification, not
assembly or electrical test evidence.

Validation on 2026-09-14: booklet build/coverage checks, `sh scripts/check.sh`,
`python3 scripts/check_docs.py` and `git diff --check` passed. The project harness
retains its existing platform-dependent skips; no physical tests were run.

Assembly details also follow [manufacturing output](../design/manufacturing-output.md),
[MOV capture](../design/mov-capture.md), [mechanical construction](../mechanical.md)
and [connector capture](../design/mains-header-capture.md). Manufacturer details
were rechecked for the [Littelfuse 215 hand-solder conditions](https://www.littelfuse.com/assetdocs/fuse-215-datasheet?assetguid=990f7193-d9a2-48e4-b760-2b43514249cf),
[TMOV lead heat sinks](https://www.littelfuse.com/assetdocs/tmov-itmov?assetguid=bd475732-1071-4352-b8aa-f78b0007eb05)
and [Phoenix 1868076 termination](https://www.phoenixcontact.com/us/products/1868076/pdf).
No universal hot-bed setting or unverified TMOV iron-temperature limit is given.

The owner subsequently confirmed the [three top stencil purchases](../../bom/purchases/W2026091502305469/README.md#ordered-stencils).
Their ordered thickness is **Select by JLCPCB**; the supplied thickness remains
unknown. The printed guide's **0.10 mm** instruction records the design-review
basis, not the confirmed order selection. Check the received stencil specification.
Actual sensor-cable specifications and internal cut lengths remain unrecorded.
The guide preserves the sensor's 203.2 mm termination-to-crimp
limit without inventing cable colours or housing-face numbering. Michael confirmed DigiKey parts, JLCPCB boards/stencils and the reviewed
AliExpress cable received on 2026-09-30 America/Vancouver in the procurement
reconciliation request. Michael reported the Mouser electronics received on
2026-10-05 America/Vancouver; Mouser cancelled the spacer line, whose allocations
use owner-held stock. Receipt does not establish assembly, cable specifications or commissioning.
Stillair's completed Hall harness is separate from this external sensor cable.
The live parts source now reflects DigiKey and Mouser stock receipt; printed PDF and its
original build/review receipts remain historical artifacts and were not regenerated. The service lead is outside the installed
three-harness build and remains covered in [service input](../design/service-input.md).

## Rebuild

Use Python with the [pinned rendering packages](source/requirements.txt);
Arial on macOS or DejaVu Sans on Linux.
From the repository root:

```sh
python3 docs/assembly/source/build_booklet.py
pdftoppm -scale-to 1400 -png docs/assembly/crystal-shim-assembly-bench-guide.pdf /tmp/crystal-shim-booklet-review
```

Review every resulting page before printing a changed PDF. The component mapping
is a reviewed purchase snapshot, not a live inventory lookup. Geometry can be
recaptured read-only on the KiCad host with:

```sh
sh pcb/tools/kicad_python.sh docs/assembly/source/extract_native.py
```

Do not silently recapture geometry if the ordered board revision changes. Reconcile
parts, orientation cues and the booklet's content with that revision first.

Printed through Executor on 2026-09-14: one Letter, duplex long-edge copy.
The Brother reported job **230 completed successfully**, followed by an empty
queue. Executor lost its completion response, so the job was verified with a
read-only IPP completed-job query; it was not submitted twice. See the
[print receipt](print-receipt.json). The physical paper has not been visually
inspected by the agent.

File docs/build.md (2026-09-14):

# One-shot build and commissioning sequence

The target is one complete, final-use set of sensor, controller and mains boards,
designed and reviewed together before a single fabrication and assembly cycle.
There is no separate sensor prototype, evaluation-board phase or planned respin.
Physical calibration and acceptance use the final boards after assembly.

1. **Complete the design basis and interfaces.** Adapt TI's sensor geometry to
   freshwater, 5 mm glass and a 50 mm physical sensing span. Define the
   18 × 64 mm below-rim PCB's thin adhesive and left-pigtail interface. Select exact
   components, footprints, mating connectors, harness pinouts, rails and GPIOs
   across all three boards. Calculate power, sensing and protection margins;
   document assumptions and checks owed on the assembled unit. No sensor hardware
   measurement is required to proceed with controller or mains design.
   Close the [refill attachment reservation](design/refill-expansion.md) before
   controller routing: three default-off pump drivers, a second buffered sensor bus
   and two accessible input pads. Capture the IRM-45-12 and 5 V buck on the power
   board, with a fused 12 V motor feed. Future accessories must fit the fixed
   12 V / 2 A aggregate allocation. Only accessories and a reservoir sensor PCB
   are added later; future feature implementation remains outside this cycle.
2. **Capture and review the complete design.** Author all three boards in
   tscircuit using `$pcb`, including explicit placement, geometry and augmentation
   manifests. Check schematic and PCB renders, datasheet pin/pad mappings, the
   sensor channel/shield geometry, enclosure fit and every board-to-board interface.
   Review mains separation and protection before routing. Select the fuse, MOV,
   RC network and filter from documented ratings and calculations before release;
   actual-load verification follows assembly.
3. **Route the accepted native boards and prepare fabrication files.** The
   compact controller, sensor and mains ECOs are accepted for routing;
   use each board's final
   native acceptance in [STATE](STATE.md), not an old initial-export receipt.
   Sensor acquisition, calibration storage, local control, retained maintenance,
   Matter/HomeKit, schedules, settings and Pushover firmware are implemented;
   physical operation still needs commissioning. Route all board connections,
   preserve the prepared planes, vias, mask/paste and isolation, and finish the
   routing-dependent return-path and USB stitching requirements. Run final ERC/DRC and fabrication review using
   `$kicad-manufacture`. Release coherent BOMs, assembly and harness drawings,
   enclosure/PCB interfaces and manufacturing outputs. G-02/G-03/G-04 govern
   fabrication release, separately from permission to start routing.
4. **Fabricate and assemble the final board set.** Use the reviewed release to
   order and assemble the three boards, enclosure and harnesses as one complete
   build, including the sensor's thin adhesive mounting. There is no
   intermediate sensor-board order or measurement-driven second fabrication phase.
   The [printed assembly bench guide](assembly/README.md) gives the exact purchased
   parts, placement maps, stencil/hot-bed versus iron steps and board/harness
   combination. Keep firmware, power-up, testing and tank mounting interactive;
   the booklet deliberately leaves those procedures out.
5. **Calibrate and commission the final low-voltage hardware.** With mains
   disconnected and a reviewed isolated low-voltage power arrangement, verify
   supplies, supported USB/service arrangements, default-off drive, sensor faults,
   retained state and watchdog behavior. Create and deliver the private
   [first configuration](design/first-configuration.md), then install the
   [Matter identity](design/matter-provisioning.md) and commission networking.
   Initial configuration leaves calibration absent, schedules empty and maintenance
   active. Fit the final sensor to the aquarium; measure rising and
   falling water, receding wet glass, adhesive gaps and mounting replacement. Record raw
   capacitances and set stop/restart margins and freshness limits through firmware.
   Verify Matter/HomeKit, window suppression, override expiry, settings persistence
   and control independence during clock/configuration/network changes. Provision
   credentials separately and verify water-transition notifications.
6. **Commission the final mains assembly and load.** After installation and
   protection review, verify actual pump starts, suppression, thermal behavior,
   leakage and loss-of-control-power response. Record measurements and actual
   fitted parts; record and resolve any failed acceptance check.
7. **Accept the installed unit.** Repeat switching with the actual aquarium, PC
   and cable routing. Establish the observation interval for receding films and
   deposits. G-01/G-05/G-06 and the G-07 observation evidence govern unattended use.

`sh scripts/check.sh` is the development gate. PCB dependencies must be installed;
the Rust toolchain installs the C6 target. [Firmware](../firmware/README.md) and
[PCB](../pcb/README.md) document individual commands. No credentials are required
for the offline checks. Matter/Wi-Fi commissioning and Pushover application/recipient
keys are supplied privately during final-unit provisioning. Do not commit them or send setup test messages.

The BOM records selected source parts and quantities for one complete unit,
separately from purchase status. Exact harness cut lengths and ordinary mounting
hardware are assembly details. No order or physical commissioning is performed
by completing a native routing handoff.

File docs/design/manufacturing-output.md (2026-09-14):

# Manufacturing output profile

**Order placed:** [W2026091502305469](../../bom/purchases/W2026091502305469/README.md).
That record holds the owner’s actual colours, via covering and final form selections;
the profile below remains the reviewed release baseline.

This is the bare-board export and order profile for all three routed native boards.
The 2026-09-14 release uses the checked outputs under each board’s
`fabrication/2026-09-14-rev1/` directory. See the release evidence before ordering.

The mains MOV ECO has a separate output directory,
`pcb/mains/fabrication/2026-09-14-mov-bulk/`. Once its current ECO review passes,
use that mains ZIP instead of the earlier rev1 mains ZIP. Controller and sensor
outputs remain in their original release directories. The MOV slot remains an
ordinary plated routed slot; no additional order-form feature is required.

## Board and assembly selection

All boards use ENIG, green mask and white silkscreen. Order bare PCBs only:
**PCB assembly: No** and **Impedance control: No**. The owner assembles all components; no assembler BOM/CPL
upload, parts consignment or custom supplier communication is required.
Use the saved apertures and tenting; do not add via filling, capping or ink plugging.
Nominal order thickness is 1.6 mm. Native stack metadata is not a substitute for
supplier construction and finished-tolerance acceptance.

| Board | Outline / copper layers | Order construction / stencil | Through-hole/pigtail hand soldering | No physical part, exclude from purchase BOM |
| --- | --- | --- | --- | --- |
| controller | 150 × 110 mm / 4 | standard four-layer No requirement stack (same nominal geometry as JLC04161H-7628); no paid USB impedance control; 0.100 mm laser-cut stencil | J1–J3, J5–J9, SW1–SW3, D4; J4 shell joints after SMT signal reflow | H1–H4, TP1–TP14 |
| sensor | 18 × 64 mm / 4 | 35 µm outer / 15.2 µm inner copper; 0.2104 / 1.065 / 0.2104 mm dielectrics, 1.6062 mm physical total; 0.100 mm stencil | Six-wire pigtail soldered to J1 after SMT | E1, J1 |
| mains | 150 × 110 mm / 2 | 1 oz outer copper, 1.51 mm FR4 core, nominal 1.6 mm total; 0.100 mm stencil | U1, K1, J1–J6, F3, D1, R1, C1, RV1 | H1–H4 |

There are no intentionally DNP physical parts. All other physical references are
SMT parts for owner assembly. On mains this is exactly U2, L1, F2 and C2–C7. Schematic-only
power flags and all board-only geometry are never procurement or placement rows.
All physical parts stay in the procurement BOM. No machine-assembly BOM/CPL
is supplied or required for this order. Keep J4 in the controller SMT list despite
its through-hole shell; do not use a blanket “exclude footprints with through
holes” filter. J4's native shell and duplicate pad paste suppression is deliberate.

Use exact `manufacturer_part_number` values from each accepted
`pcb/<board>/design/handoff.lock.json` manifest, verified against native `MPN`
fields. [bom/bom.csv](../../bom/bom.csv) records purchase status and offboard parts;
it is not a substitute for per-board reference/quantity reconciliation. Purchase
exact parts from component distributors for owner assembly. Do not silently substitute values,
packages or connector variants. Sensor `PCB-COPPER-OOP-50` and
`PCB-SENSOR-PIGTAIL-6` identify board features, not purchasable parts.

Sensor stencil thickness is now selected as 0.100 mm. The smallest native
apertures are U1's 1.45 × 0.30 mm rounded rectangles (0.05 mm corner radius):
area 0.432854 mm², perimeter 3.414159 mm, area ratio 1.26782 at this thickness,
above the 0.66 process screen. All 42 paste apertures have zero effective margin;
E1/J1 have no paste. This is an engineering process selection, not measured
paste-transfer performance. Supplier process and final CAM acceptance remain
checks for all three stencils.

## Final checks and output path

Run `sh scripts/check-routing.sh <board> --final` for all three boards. This
checks native PCB DRC/connectivity, PCB-to-schematic parity and the routing
supplement; it does not run strict ERC or source parity. Run the separate
`verify-schematic-cleanup` and `snapshot-kicad` commands below for those gates.
Require zero unconnected items. The sensor's six exact item-bound inner-pad
warnings are the only declared finding exclusions; the routing checker verifies
their identities. Initial ignored DRC categories are not blanket release waivers. The final
[strict-category audit](evidence/pre-fab-2026-09-14/strict-drc-review.md) checks
the five saved ignored categories analytically, with exact affected items and
limitations. Native DRC severity changes were unavailable through the exposed
API; that audit is not described as a strict-severity native DRC pass.
Preserve the accepted stack, pours, fixed sensor copper, plane connections and
prepared breakout segments. Perform the routed review in the
[PCB skill](../../.agents/skills/pcb/SKILL.md), including insulation and USB/rail
constraints. Save and refill before the final reports and exports.

## Release files and order form

Generate the release with `python3 pcb/tools/release/export-2026-09-14.py` only
after current validation. The script uses KiCad CLI, checks filled zones, verifies
that native bytes remain unchanged and writes hashes and command results.

Each `pcb/<board>/fabrication/2026-09-14-rev1/` contains:

- `crystal-shim-<board>-rev1-jlcpcb.zip`: the only PCB fabrication upload.
  Four/two copper layers, both mask and silk layers, Edge.Cuts, separate PTH/NPTH
  Excellon drills. No paste layers or Gerber-job stack metadata in this ZIP.
- `stencil/`: the separate F.Paste Gerber for a 0.10 mm top-only laser-cut stencil.
- `assembly/`: schematic PDF and native fabrication/silk/mask drawing for owner assembly.
- `evidence/`: native/output checksums, commands and CAM views parsed from the ZIP.

Use one order line per board, with these normal selections on the
[JLCPCB form](https://cart.jlcpcb.com/quote), checked 2026-09-14:

| Setting | Controller | Sensor | Mains |
| --- | --- | --- | --- |
| Material | FR-4 | FR-4 | FR-4 |
| Product type / Different designs | Industrial/Consumer / 1 | Industrial/Consumer / 1 | Industrial/Consumer / 1 |
| Layers | 4 | 4 | 2 |
| Dimensions | 150 × 110 mm | 18 × 64 mm | 150 × 110 mm |
| Quantity | 5 | 5 | 5 |
| Delivery format | Single PCB | Single PCB | Single PCB |
| Thickness | 1.6 mm | 1.6 mm | 1.6 mm |
| Outer copper | 1 oz | 1 oz | 1 oz |
| Inner copper | 0.5 oz | 0.5 oz | Not applicable |
| Mask / silkscreen | Green / White | Green / White | Green / White |
| Surface finish | ENIG | ENIG | ENIG |
| Impedance control | No | No | No |
| Stackup | No requirement | No requirement | Standard 2-layer |
| Via covering | Tented | Tented | Tented |
| PCB assembly | No | No | No |
| Gold fingers / castellations / edge plating | No | No | No |
| Electrical test | Flying probe | Flying probe | Flying probe |
| Marking | Remove order number | Remove order number | Remove order number |

Five bare boards each is the suggested standard minimum batch; the parts list
populates **one set**, with optional spares shown separately. Additional assembled
sets need multiplied part quantities. Keep other advanced process options at their
ordinary defaults. Select no via filling, plugging, capping, blind/buried vias,
controlled depth, countersinks or custom stackup. The plated slots are ordinary
Excellon routed slots, not a special process. Leave special instructions empty.

The four-layer No requirement construction currently has the same published
nominal geometry as the historical JLC04161H-7628 basis; do not request that named
impedance template or upload an impedance requirement. See the
[manufacturing review](evidence/pre-fab-2026-09-14/manufacturing-review.md).
The native dielectric loss/mask defaults are nonbinding CAD metadata.

Order one **top-only, 0.10 mm, laser-cut stainless stencil** per board for owner
paste/reflow. A standard non-framework stencil with ordinary size/electropolishing
options suffices; upload the corresponding F.Paste file. No custom aperture edits
or bottom stencil are needed. Follow the saved nine-window U1 ground pattern and
USB shell/duplicate-contact suppression. The stencil is separate from PCB assembly.

Use [the consolidated purchase list](../../bom/order-2026-09-14/README.md), whose
exact MPNs, references and quantities reconcile to all physical native components.
No-part mounting holes, test pads, sensor electrodes and pigtail lands are excluded.
The harness and mounting stock are included separately from PCB component counts.

Inspect the upload preview for the stated dimensions/layer count and check it
against these CAM views. The supplier’s live quote/DFM must accept these standard
settings; no quote, paid order or returned supplier CAM has been approved here.
If the fabricator requests a material change, compare it with this release before
accepting it. Physical assembly, sensor calibration, USB operation, isolation and
loaded commissioning remain the checks in the project test matrix.

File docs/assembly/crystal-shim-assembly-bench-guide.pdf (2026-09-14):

CRYSTAL SHIM / ASSEMBLY

# Start with the flat parts

Stencil + hot bed first. Iron after cooling. Build one sensor, one controller and one mains board.

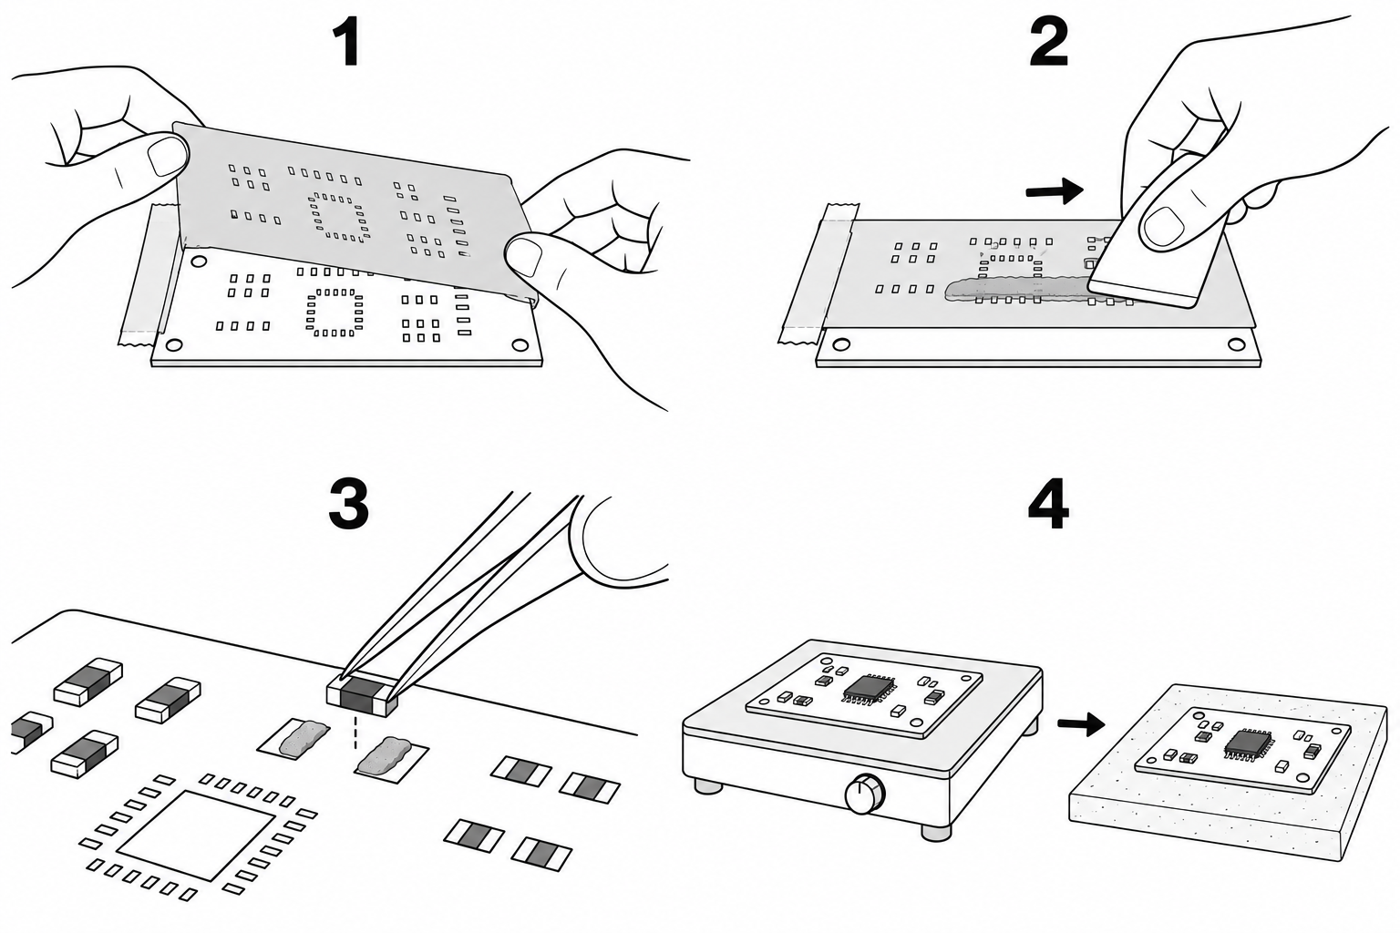
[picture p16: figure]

REV 1 • ONE SET • 14 SEP 2026 | 01
1 ALIGN | 2 PASTE | 3 PLACE | 4 REFLOW + COOL
Support the bare board level. Tape the 0.10 mm top stencil as a hinge; align every opening with its pad. | Pull one thin, even print. Lift vertically. Correct a smeared print before placing components. | Use labelled bags and the placement maps. Small ICs and passives first, then larger SMT parts. | Use the paste maker’s temperature profile. Measure board temperature. Let solder solidify before moving.

The order for this build

Sensor SMT → controller SMT → mains SMT → all iron work → harnesses → lower board wiring → separator → controller. Each board is a separate hot-bed run.

Keep this beside the bench

All assembly is unpowered. Leave firmware, power-up, testing and tank mounting for our interactive sessions. Quantities here make one set, even though five bare boards of each type were ordered.

# Recognize the SMT packages

Drawings identify package families. The bag’s exact MPN determines the part; similar-looking parts are not interchangeable.

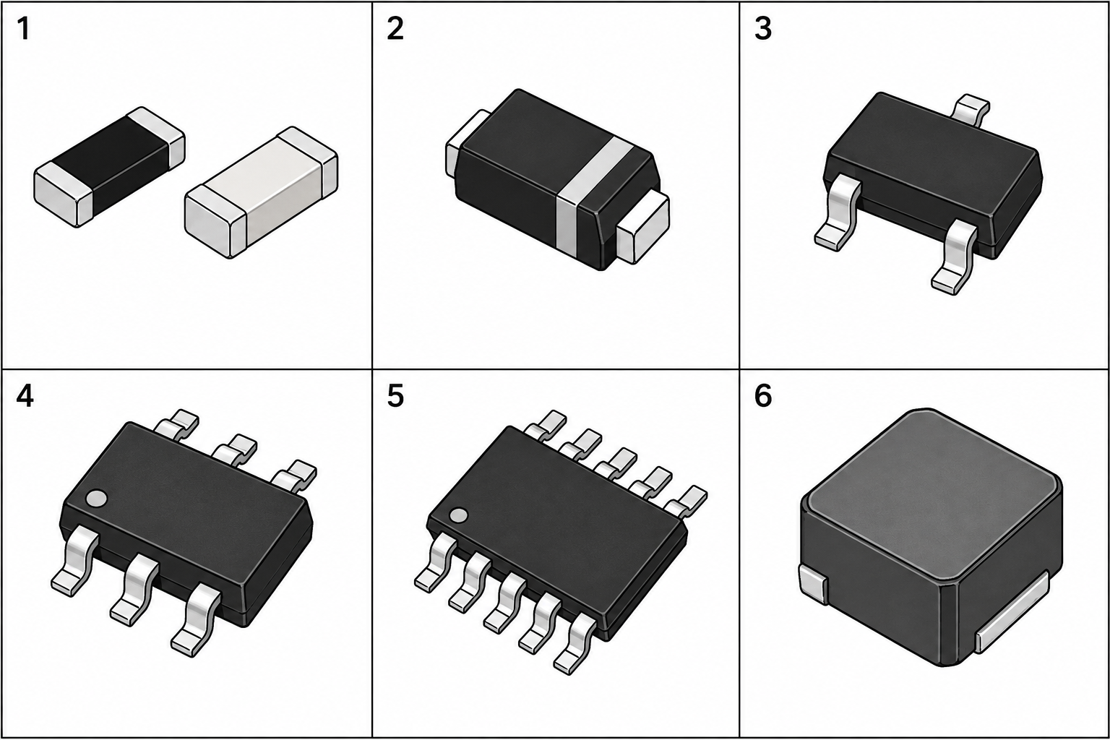
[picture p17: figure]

PICTURE | WHAT YOU WILL SEE | USE THE MAP FOR…
1 Chip passives | Resistors; unmarked ceramic capacitors. All are nonpolar. | Exact value and size. 0603, 0805, 1206 and 1210 are different bodies.
2 Diode | STPS2L40U and SMBJ7.0A have a cathode band. | Band at the black dot on D references.
3 Three leads | AO3400A transistors Q1–Q4 on the controller. | Two-leg side down, lone leg up in the top-view maps.
4 Small IC | Five- and six-lead ICs share this general outline. | Exact MPN and manufacturer’s pin-1 identifier.
5 Fine-pitch IC | FDC1004 and FSUSB42 are ten-lead parts; TCA9517 has eight. | Pin 1. Do not use body text direction as the orientation cue.
6 Inductor | SRP5030TA-4R7M, one on each large board; nonpolar. | Controller L1 and mains L1.

Map key

All maps look down at the component side and are never mirrored. A black dot marks IC/MOSFET pin 1 or diode/LED cathode. Pale outlines are neighbouring parts. Drawings are enlarged, not solder stencils.

# Sensor / all 14 parts reflow

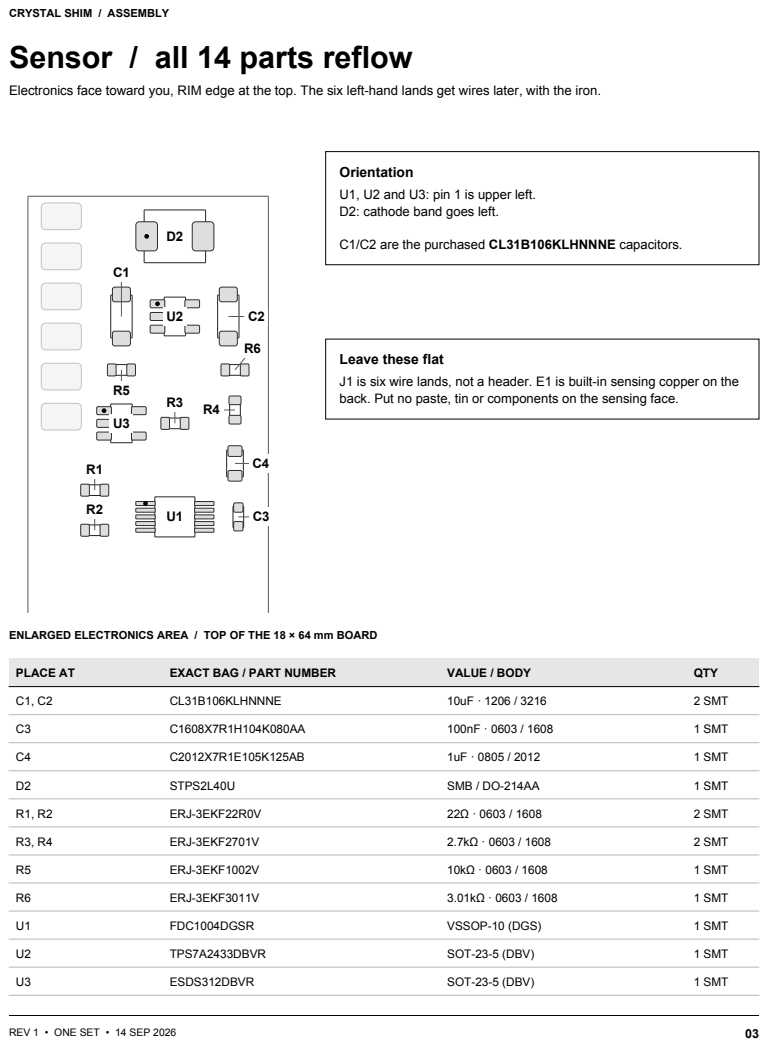
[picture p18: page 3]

Electronics face toward you, RIM edge at the top. The six left-hand lands get wires later, with the iron.

Orientation
U1, U2 and U3: pin 1 is upper left.
D2: cathode band goes left.

C1/C2 are the purchased CL31B106KLHNNNE capacitors.

Leave these flat
J1 is six wire lands, not a header. E1 is built-in sensing copper on the
back. Put no paste, tin or components on the sensing face.

ENLARGED ELECTRONICS AREA / TOP OF THE 18 × 64 mm BOARD

# Controller / iron parts + area map

A

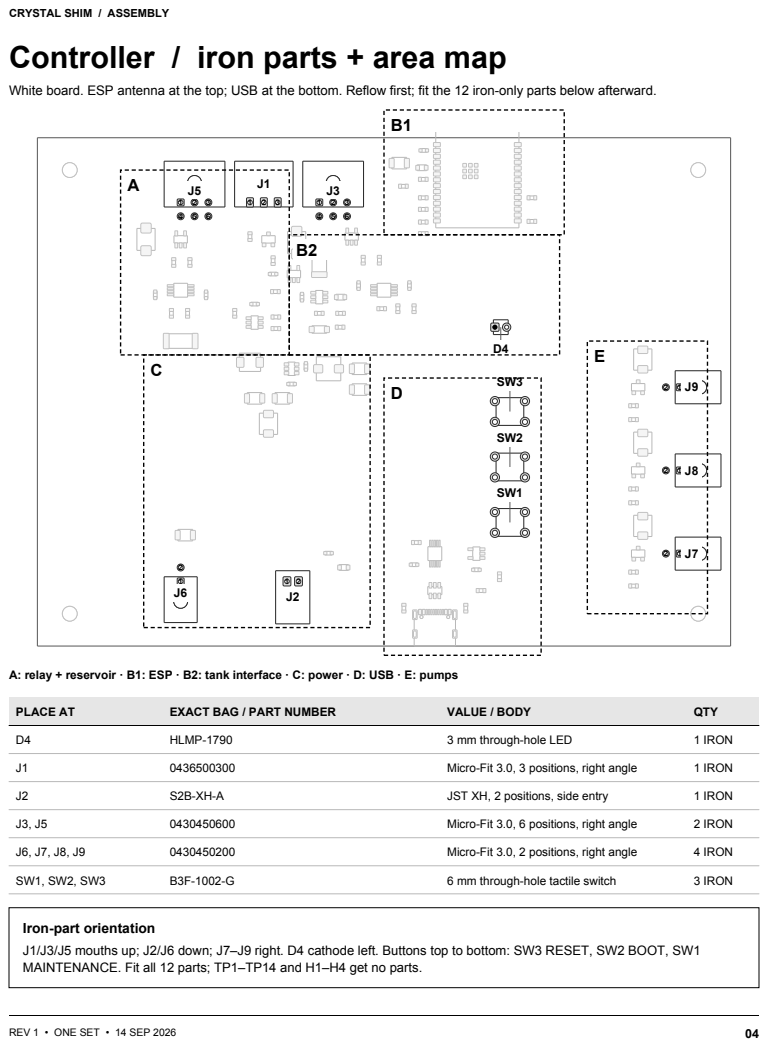
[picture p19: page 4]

White board. ESP antenna at the top; USB at the bottom. Reflow first; fit the 12 iron-only parts below afterward.

A: relay + reservoir · B1: ESP · B2: tank interface · C: power · D: USB · E: pumps

Iron-part orientation
J1/J3/J5 mouths up; J2/J6 down; J7–J9 right. D4 cathode left. Buttons top to bottom: SW3 RESET, SW2 BOOT, SW1
MAINTENANCE. Fit all 12 parts; TP1–TP14 and H1–H4 get no parts.

# Controller A / Relay + reservoir interface

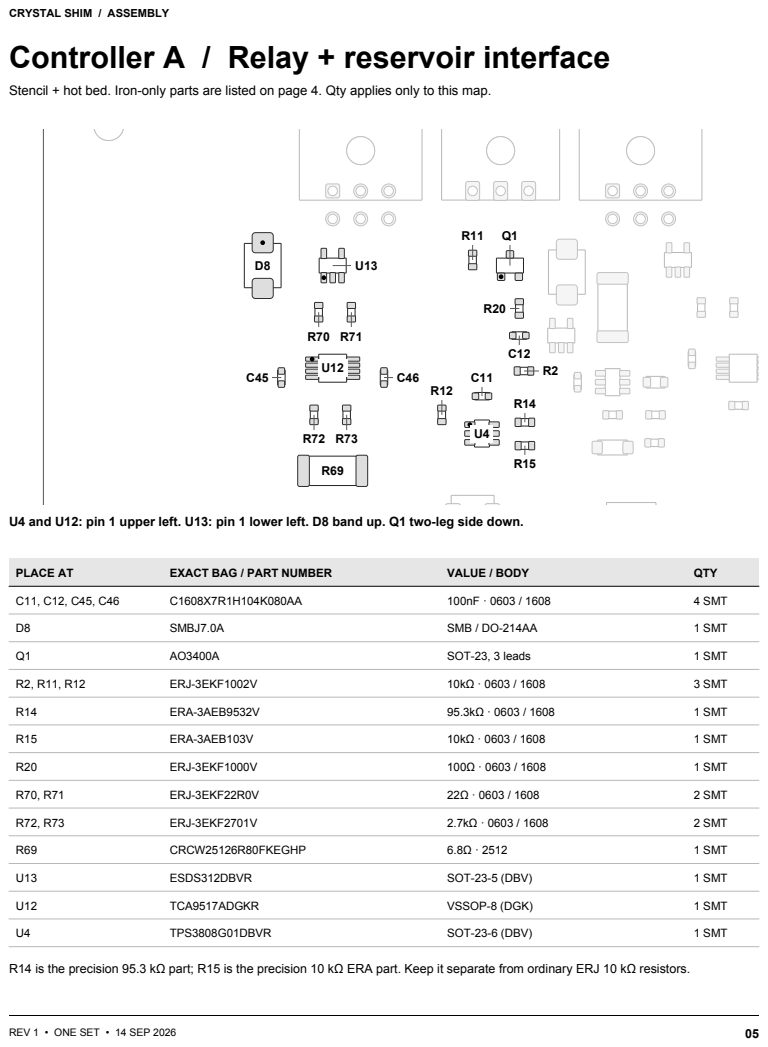
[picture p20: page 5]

Stencil + hot bed. Iron-only parts are listed on page 4. Qty applies only to this map.

U4 and U12: pin 1 upper left. U13: pin 1 lower left. D8 band up. Q1 two-leg side down.

R14 is the precision 95.3 kΩ part; R15 is the precision 10 kΩ ERA part. Keep it separate from ordinary ERJ 10 kΩ resistors.

# Controller B1 / ESP module + nearby passives

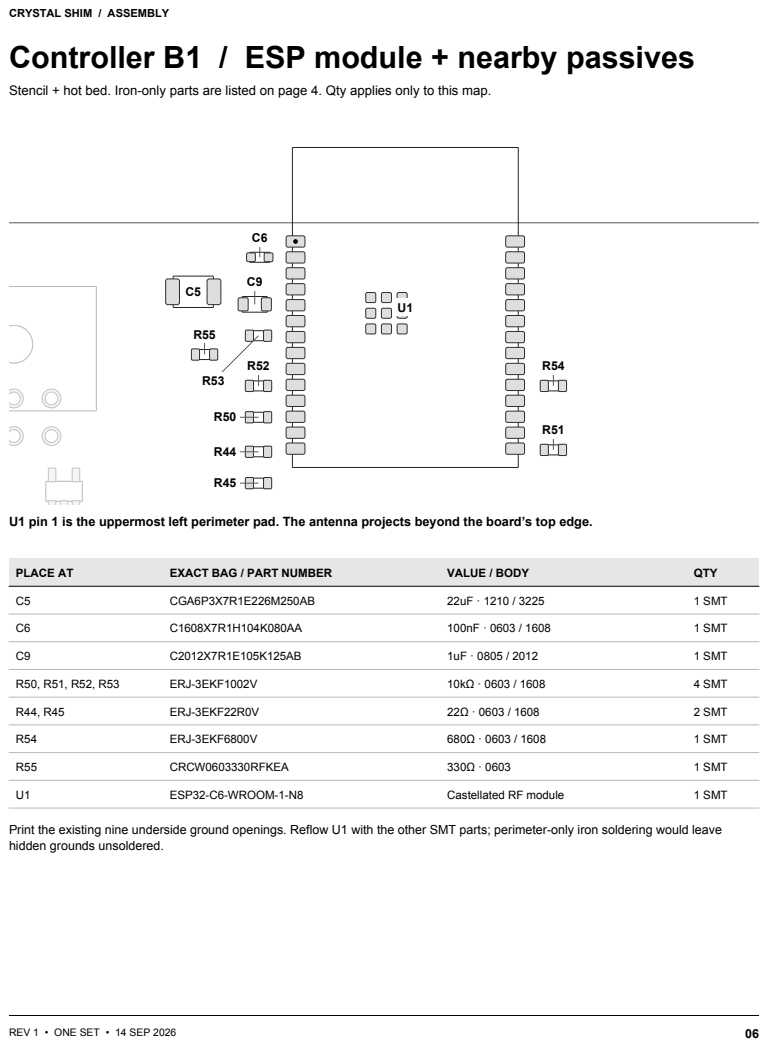
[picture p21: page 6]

Stencil + hot bed. Iron-only parts are listed on page 4. Qty applies only to this map.

U1 pin 1 is the uppermost left perimeter pad. The antenna projects beyond the board’s top edge.

Print the existing nine underside ground openings. Reflow U1 with the other SMT parts; perimeter-only iron soldering would leave
hidden grounds unsoldered.

# Controller B2 / Tank sensor interface + LED

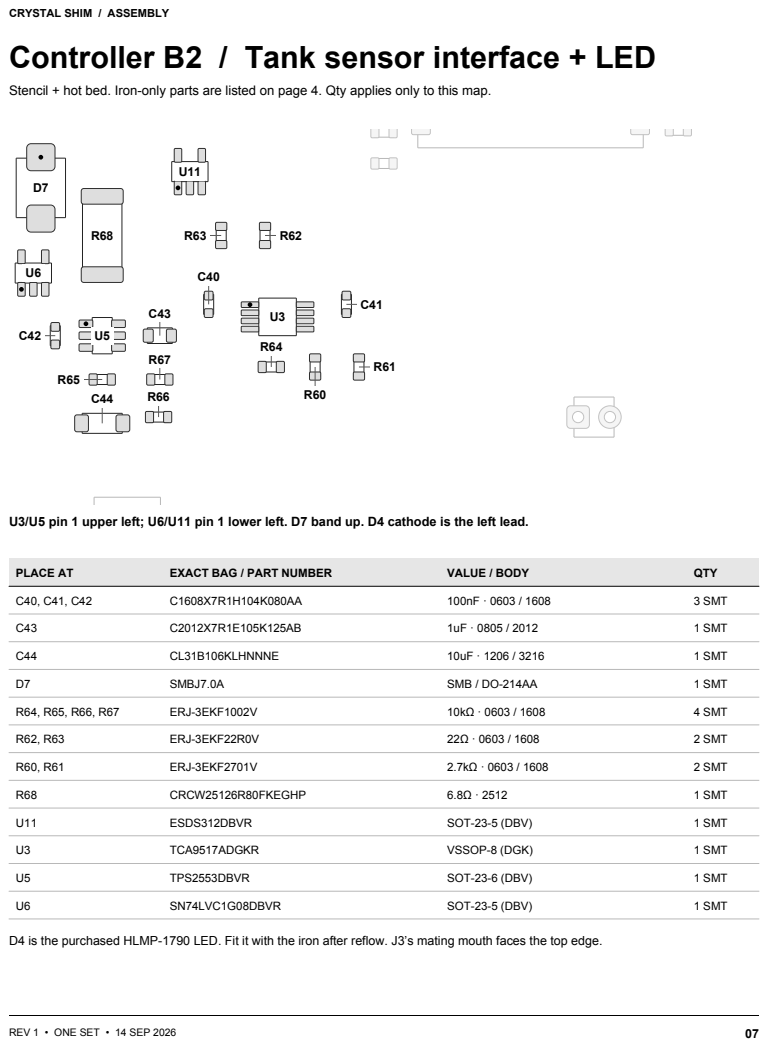
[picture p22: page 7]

Stencil + hot bed. Iron-only parts are listed on page 4. Qty applies only to this map.

U3/U5 pin 1 upper left; U6/U11 pin 1 lower left. D7 band up. D4 cathode is the left lead.

D4 is the purchased HLMP-1790 LED. Fit it with the iron after reflow. J3’s mating mouth faces the top edge.

# Controller C / Power + service connectors

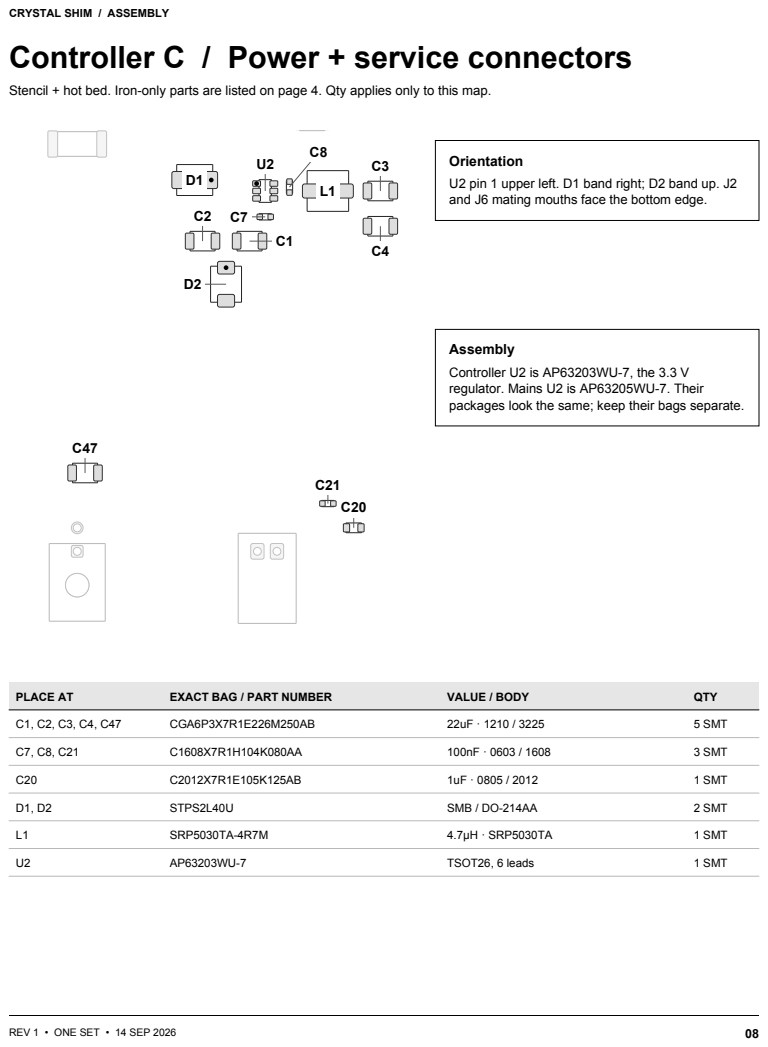
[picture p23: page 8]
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

U2 pin 1 upper left. D1 band right; D2 band up. J2
and J6 mating mouths face the bottom edge.

Assembly
Controller U2 is AP63203WU-7, the 3.3 V
regulator. Mains U2 is AP63205WU-7. Their
packages look the same; keep their bags separate.

# Controller D / USB + pushbuttons

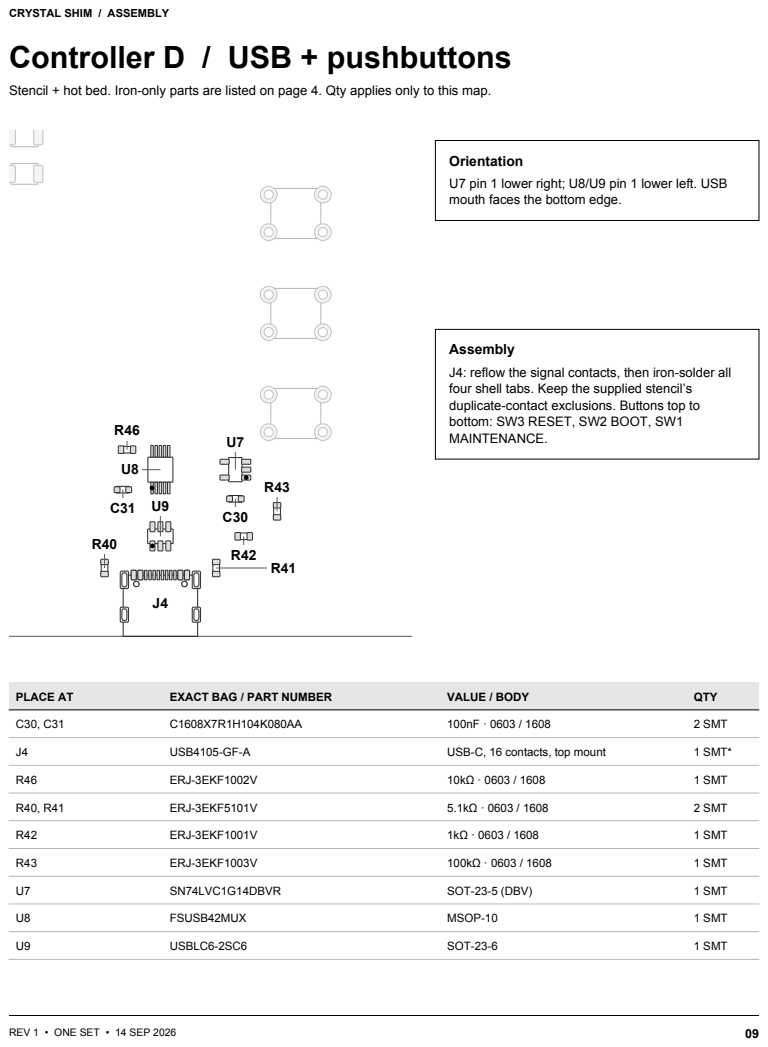
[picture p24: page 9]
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

Orientation
U7 pin 1 lower right; U8/U9 pin 1 lower left. USB
mouth faces the bottom edge.

Assembly
J4: reflow the signal contacts, then iron-solder all
four shell tabs. Keep the supplied stencil’s
duplicate-contact exclusions. Buttons top to
bottom: SW3 RESET, SW2 BOOT, SW1
MAINTENANCE.

# Controller E / Three pump drivers

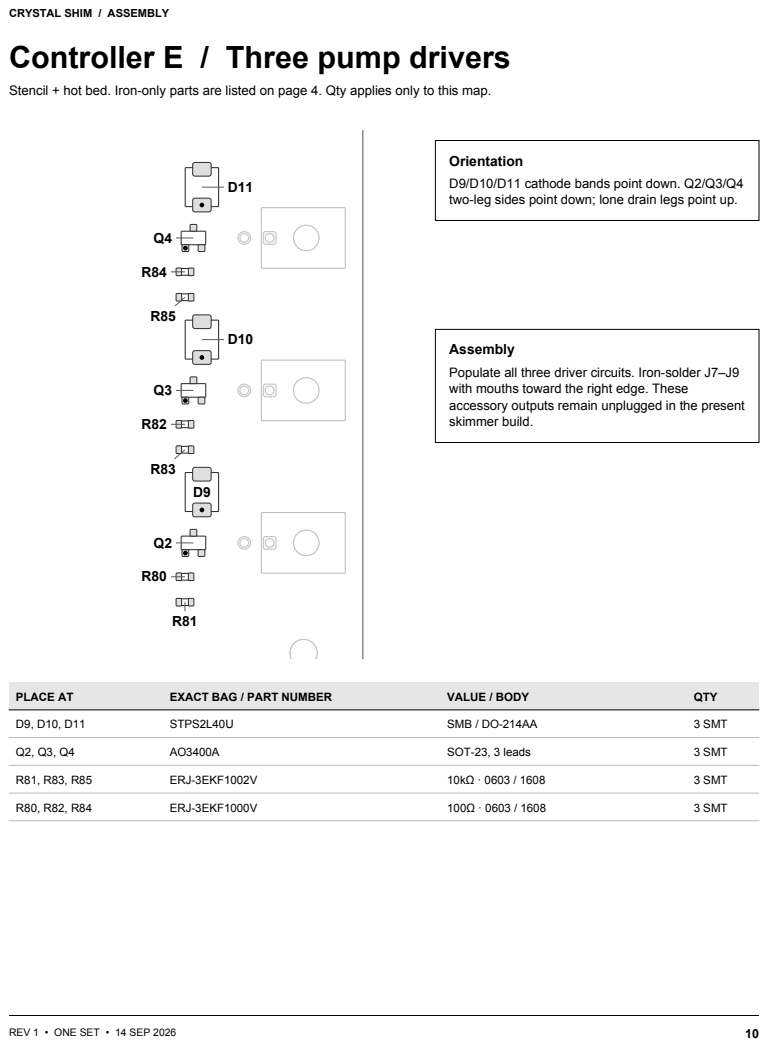
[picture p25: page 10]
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

Orientation
D9/D10/D11 cathode bands point down. Q2/Q3/Q4
two-leg sides point down; lone drain legs point up.

Assembly
Populate all three driver circuits. Iron-solder J7–J9
with mouths toward the right edge. These
accessory outputs remain unplugged in the present
skimmer build.

# Mains / nine SMT parts first

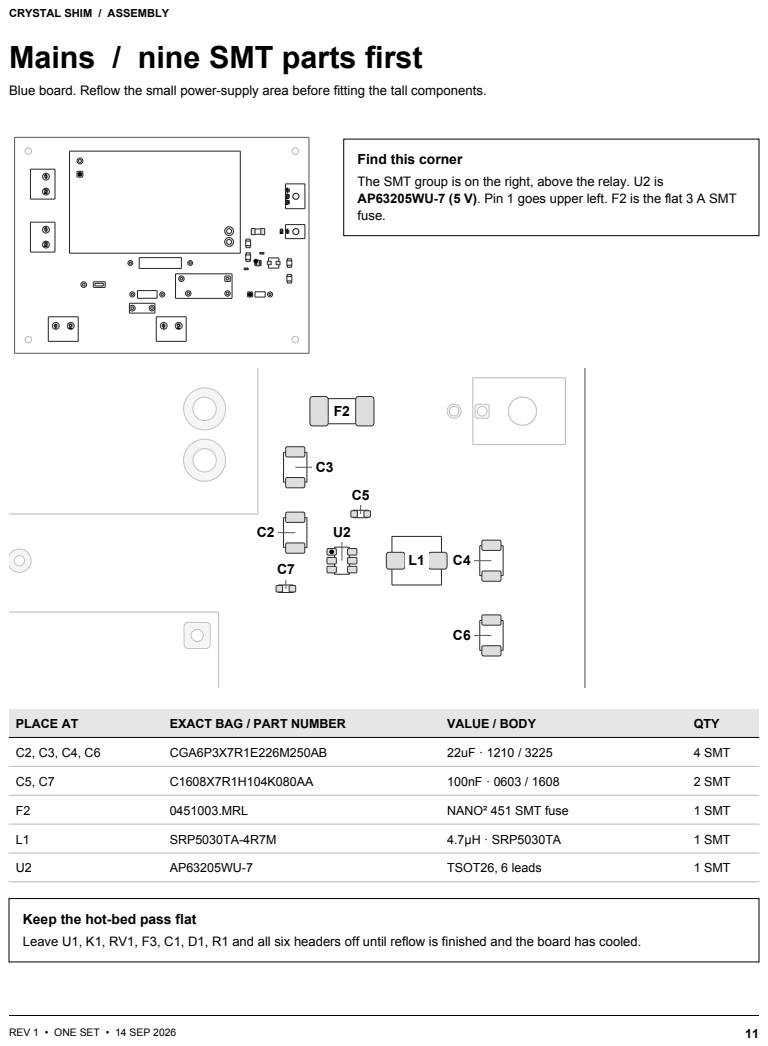
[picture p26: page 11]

Blue board. Reflow the small power-supply area before fitting the tall components.

Find this corner
The SMT group is on the right, above the relay. U2 is
AP63205WU-7 (5 V). Pin 1 goes upper left. F2 is the flat 3 A SMT
fuse.

Keep the hot-bed pass flat
Leave U1, K1, RV1, F3, C1, D1, R1 and all six headers off until reflow is finished and the board has cooled.

# Recognize the iron-soldered parts

Generic body shapes, not pin-layout drawings. Exact positions and orientations are on the board maps.

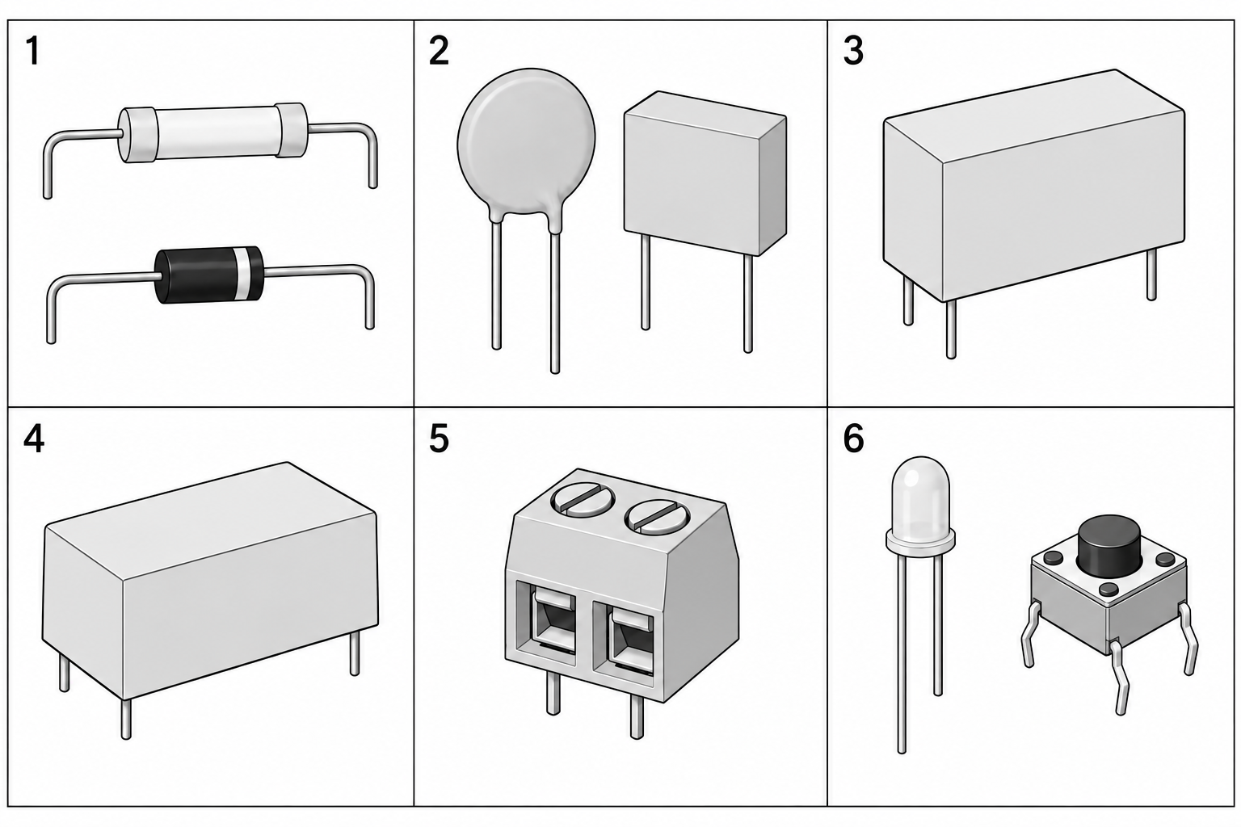
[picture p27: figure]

PICTURE | EXACT PART | PLACE AT
1 Axial bodies | PR02FS0201000KR500 · 100 Ω fusible resistor 1N4007-E3/54 · banded diode | Mains R1 Mains D1
2 Disc + box | TMOV14RP175E · thermal MOV B32921C3473K000 · 47 nF safety capacitor | Mains RV1 Mains C1
3 Relay | G5RL-1A-TV8 DC5 · 5 V coil | Mains K1
4 AC/DC module | IRM-45-12 · large encapsulated PSU | Mains U1
5 Screw terminals | 1868076 · two positions, right-angle wire entry | Mains J1–J4
6 LED + buttons | HLMP-1790 · green 3 mm LED B3F-1002-G · four-lead pushbuttons | Controller D4 Controller SW1–SW3

Other iron parts

F3 is the leaded 0215001.MXEP fuse. Molex and JST board connectors are keyed plastic housings with solder tails. Use each map’s mating-direction cue and the board’s body outline; do not force a rotated connector.

# Mains / fit the tall parts

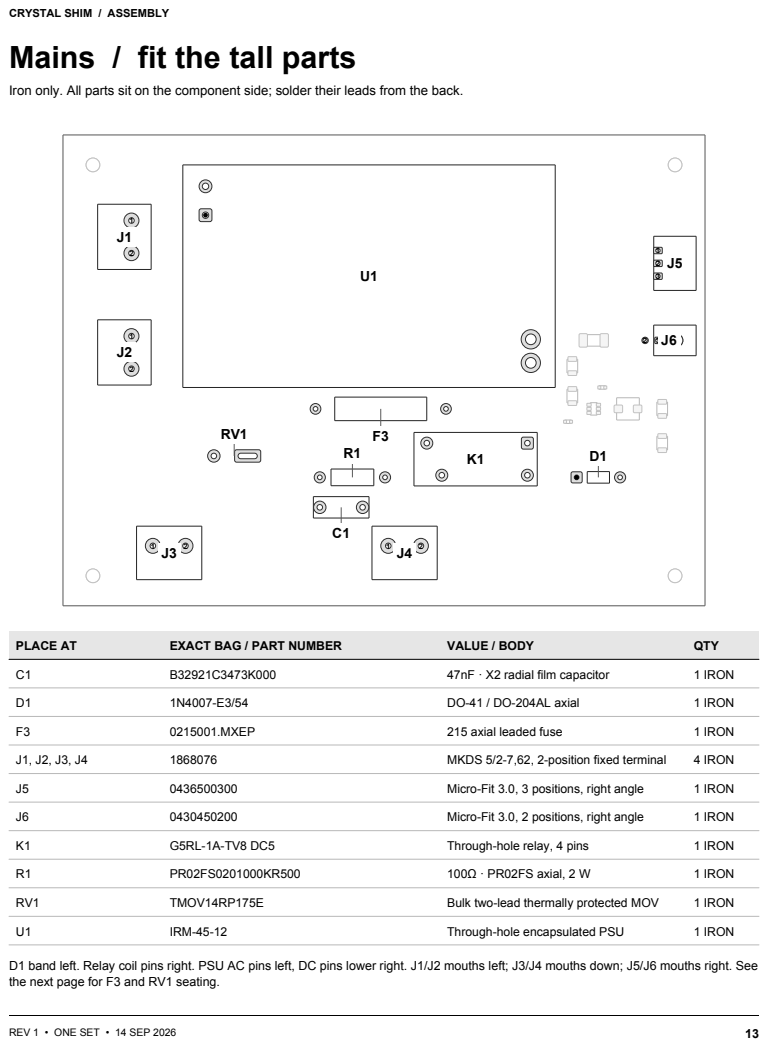
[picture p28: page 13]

Iron only. All parts sit on the component side; solder their leads from the back.

D1 band left. Relay coil pins right. PSU AC pins left, DC pins lower right. J1/J2 mouths left; J3/J4 mouths down; J5/J6 mouths right. See
the next page for F3 and RV1 seating.

# Iron work / fit, solder, trim

After each board has cooled, fit low through-hole parts first and the largest bodies last.

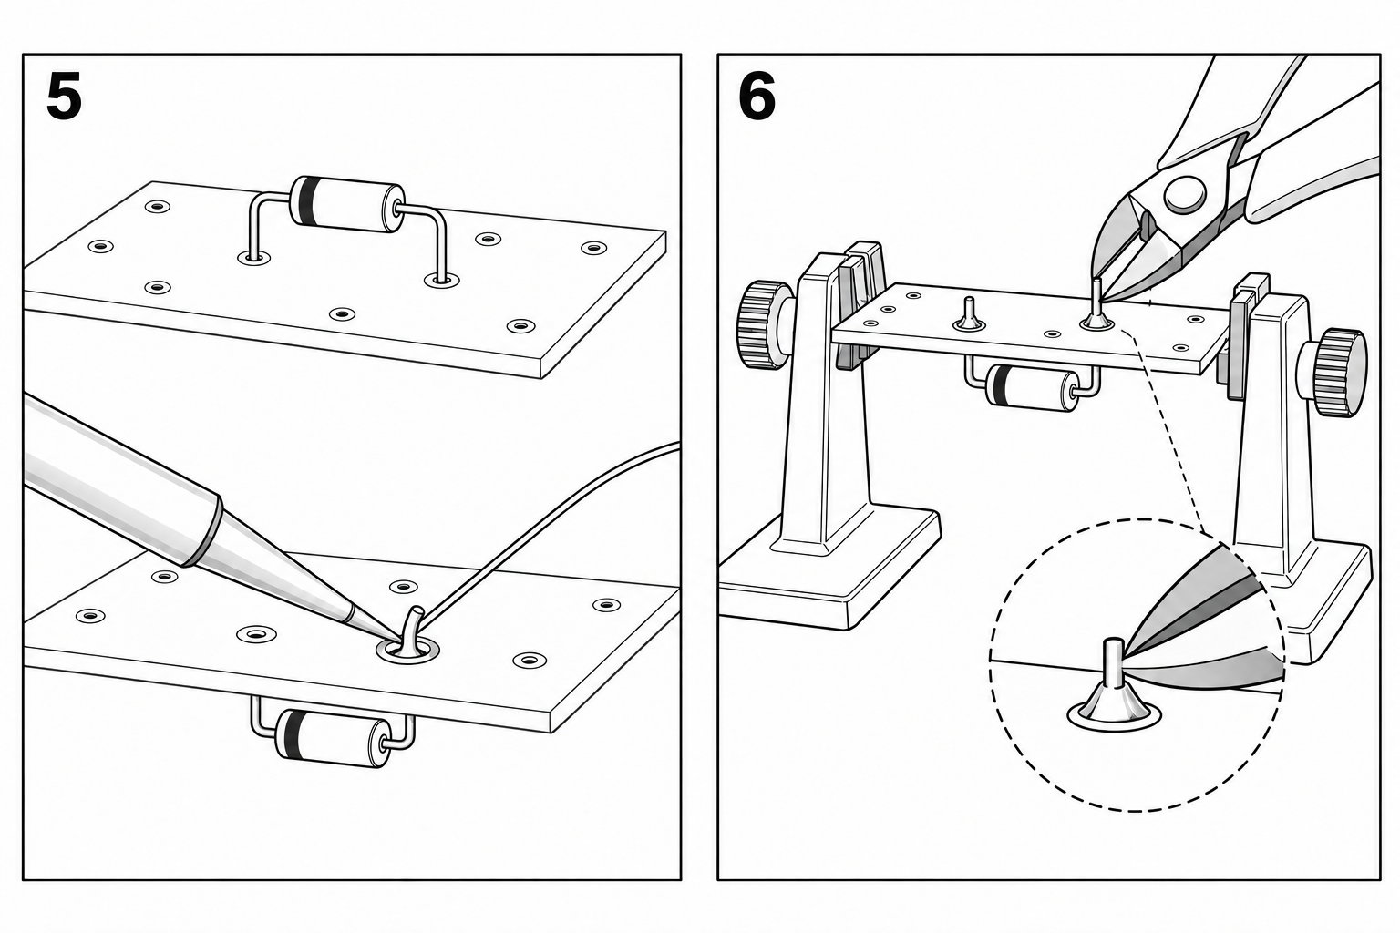
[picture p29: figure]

5 FIT + SOLDER | 6 TRIM + FINISH
Fit one part, secure it, and turn the board over. Heat pad and lead together, then feed solder into the joint. Keep the board supported clear of its components. | Cut the lead above the solder fillet; hold the offcut. Keep mains lead/solder projections within 2 mm of the underside. Clean SMT work before installing the non-washable switches and relay.

F3: axial T1A fuse / 0215001.MXEP

Seat the fuse at least 1.5 mm above the board. Make bends more than 1 mm from its end caps. Its maker specifies an iron at 350 °C ±5 °C for at most 5 seconds. Do not reflow it.

RV1: thermal MOV / TMOV14RP175E

Fit after reflow. Keep its unbent, staggered leads; rotate the upright body to match the round hole and slot. Support 0.5–1.0 mm above the board and heat-sink each lead while soldering. Do not force or reshape the leads.

RV1 final fit: upright within 5°, yaw at most 35°, top at most 26 mm above the PCB; entire body/leads/solder stay inside its 27 × 27 mm assembly envelope. Keep solder and offcuts out of isolation gaps.

# Wire the three connections

One sensor lead and two internal harnesses. Circuit maps below are symbolic, not housing-face views.

INTERNAL BOARD-TO-BOARD HARNESSES

MAINS J5 | CONTROLLER J1 | MAINS J6 | CONTROLLER J6
HARNESS | SAME CIRCUIT AT BOTH
ENDS
WIRE | EXACT BAG / FITTED SET

Mains J5
to controller J1

1 → 1: +5 V
2 → 2: GND
3 → 3: COIL_DRAIN

22 AWG
Red / black / blue

2 × 0436450300 housings
6 × 0430300007 contacts
(Molex 43645-0300 / 43030-0007)

Mains J6
to controller J6

1 → 1: +12 V
2 → 2: GND

20 AWG
Red / black

2 × 0430250200 housings
4 × 0430300007 contacts
(Molex 43025-0200 / 43030-0007)

Keep the 12 V pair together through its own harness. J7–J9 on the controller are future pump outputs; their pin 2 is a switched return. Feed the controller at J6.

SENSOR J1 → CONTROLLER J3

Fit 1 × 0430250600 housing and 6 × 0430300007 contacts at the controller end (Molex 43025-0600 / 43030-0007). The sensor end solders directly to J1.

OUTWARD FACE

Sensor J1

1

2

3

4

5

6

Exit left

Land 1 is at the top.
Solder only on this face.
SENSOR LAND → J3 | FUNCTION | TWISTED PAIR
1 → 1 | +5 V sensor supply | 1 + 4
2 → 2 | SDA | 2 + 5
3 → 3 | SCL | 3 + 6
4 → 4 | Power ground return | 1 + 4
5 → 5 | SDA ground return | 2 + 5
6 → 6 | SCL ground return | 3 + 6

Use 24 AWG, three twisted pairs. Identify the actual cable pairs and label both ends 1–6 before separating them. Keep all three ground returns. Cut back and insulate any overall foil or drain at both ends.

203.2 mm maximum, including the ends

Measure from sensor solder termination to controller crimp, including internal routing and strain relief. Cut to the installed route. The ordered cable's model and specifications are unrecorded; identify its pairs and confirm contact fit before termination. Match circuit numbers, not an assumed left-to-right cavity order.

# Connect mains, filter and PE

Keep every power source disconnected. This is a connection map, not a literal wire route.

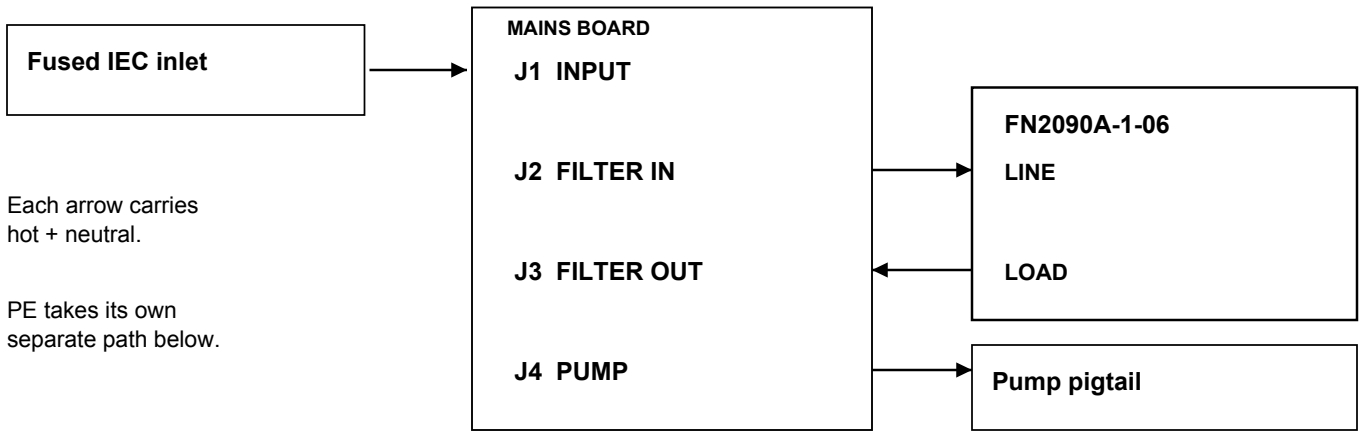
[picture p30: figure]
MAINS BOARD; J1 INPUT; J2 FILTER IN; J3 FILTER OUT; J4 PUMP; Fused IEC inlet; LINE; LOAD; Pump pigtail; Each arrow carries hot + neutral.; PE takes its own separate path below.

MAINS BLOCK | PIN 1 · HOT (L) | PIN 2 · NEUTRAL (N)
J1 · INPUT | From inlet fused L output | From inlet N
J2 · FILTER IN | To filter LINE L | To filter LINE N
J3 · FILTER OUT | From filter LOAD L | From filter LOAD N
J4 · PUMP | To output-pigtail hot | To output-pigtail neutral

PE bypasses the boards. Three separate branches meet at one covered M4 metal junction. Keep PE separate from neutral; neither PE nor neutral is switched.

PE BRANCH | EQUIPMENT END | M4 JUNCTION END
Inlet PE | TE 2-520184-2 FASTON | TE 31886 ring
Filter PE blade | TE 2-520184-2 FASTON | TE 31886 ring
Output pigtail PE | Existing pigtail conductor | TE 320551 ring

Offboard parts: Schurter 6200.23 inlet; Littelfuse 0215002.MXP 2 A fuse; 3-125-661 (RC320) rear cover; FN2090A-1-06 filter; 1112.048.005350 output pigtail; M3231 gland and 8463 locknut.

Fit 8 × TE 2-520184-2 insulated 6.35 mm receptacles: inlet L/N/PE (3), filter LINE/LOAD L/N (4), filter PE (1). Use 18 AWG, 600 V, 105 °C mains/PE wire. The four Phoenix Contact 1868076 PCB blocks take wire directly.

Finish the lower wiring before fitting the separator

Strip 8 mm; tighten to 0.5–0.6 N·m, supporting the terminal body. Keep filter LINE/LOAD apart and 8 mm between primary wiring and SELV. Clamp PE rings metal-to-metal on separate insulating support; exclude plastic from the electrical clamp. Fit both covers.

# Combine the finished boards

Controller above mains, both component sides up. Fit all primary wiring before closing the stack.

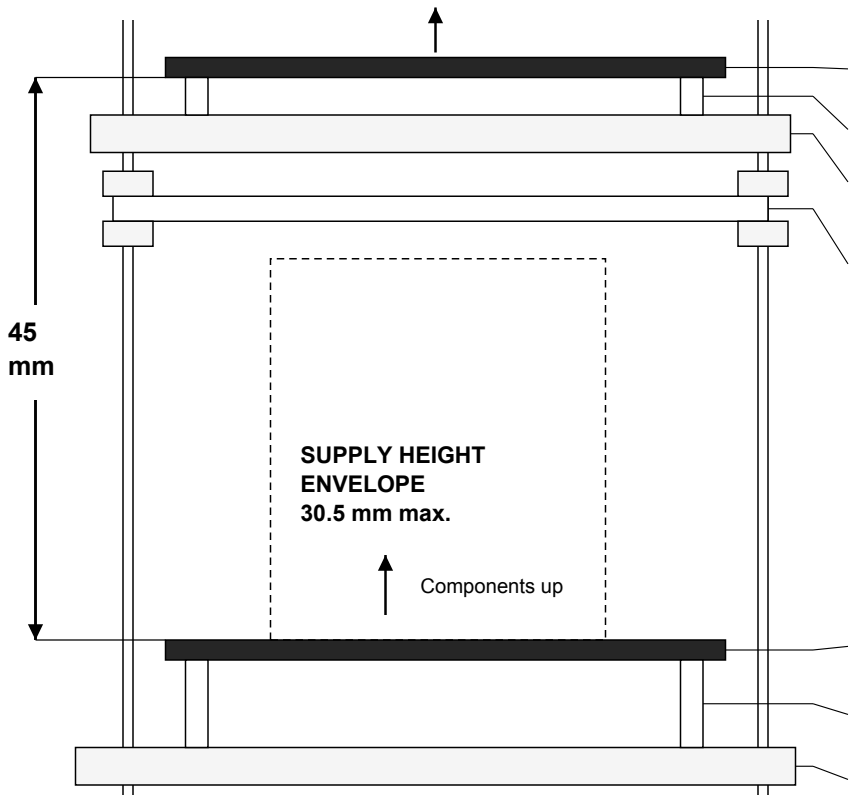
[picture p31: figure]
SUPPLY HEIGHT ENVELOPE 30.5 mm max.; Components up

SIDE PROJECTION · WIDTHS SIMPLIFIED

CONTROLLER
150 × 110 mm; components up

Plain 3 mm spacers

Two FR-4 H-shaped rails

Intact 2 mm separator
158 × 118 mm; edge-clamped

Four external M4 nylon rods support the rails and separator tabs.

45 mm is measured from the mains top face to the controller underside.

MAINS BOARD
150 × 110 mm; components up

Plain 7 mm spacers

### 3 mm FR-4 carrier

COMBINE IN THIS ORDER

STEP | ACTION
1 | Finish mains J1–J4 wiring and all three PE branches. Fit the inlet and PE covers while the terminal screws remain accessible.
2 | Mate both internal harnesses at mains J5 and J6. Carry them around the isolated edge, clear of primary wiring and the antenna reserve.
3 | Capture the intact separator between its corner tabs. Fit the H rails, plain 3 mm spacers and controller using insulating through-bolts.
4 | Mate controller J1 (5 V/coil), J6 (12 V) and J3 (sensor). Leave future reservoir J5 and pump outputs J7–J9 empty.

Use the four aligned M3 PCB positions. Keep the separator intact, with no holes or antenna notch. Use single through-bolts through plain spacers; include washers in the effective spacing. The 45 mm face gap is not a 45 mm spacer length.

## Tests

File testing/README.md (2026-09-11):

# Commissioning evidence

[test-matrix.csv](test-matrix.csv) holds the planned design reviews and hardware
acceptance tests.
Every row starts `Not run`, with blank evidence, owner and date. Do not turn host
tests or generated reports into physical test passes. Record board/firmware
revision, apparatus, observations and linked evidence when a test is performed.

Physical checks use the final boards and installed unit after the single
fabrication/assembly cycle. They do not require a separate prototype or
sensor-only board order. G-02/G-03/G-04 cover design and fabrication review;
G-01/G-05/G-06 cover the assembled hardware, and G-07 covers unattended use.
Gate IDs are not chronological. Low-voltage checks use the final hardware with
mains disconnected before the completed mains assembly is commissioned.

The matrix defines proposed methods and acceptance intent. Where numerical limits
or an observation duration are open, establish them before claiming that gate
passed. Prefixes: `SEN` sensor, `PWR` supply/USB, `CTL` control, `MAI` mains,
`EMI` interference, `INS` installation, `NOT` water-transition notifications.

The development gate is `sh scripts/check.sh`. Its host simulation and tool tests
are software evidence only. Physical work follows [docs/build.md](../docs/build.md)
and the review gates in [docs/decisions.md](../docs/decisions.md).

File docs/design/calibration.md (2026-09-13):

# Sensor calibration and validity

Implemented in [`firmware/core/src/calibration.rs`](../../firmware/core/src/calibration.rs).
This is the pure conversion and validity stage between complete FDC1004 frames
and the supervisor. It contains no driver, persistent-storage codec, calibration
UI, physical calibration values, or assumption that the current electrode
geometry has passed commissioning.

## Measurement model

The board keeps LEVEL and the always-wet liquid reference RL. It omits the
optional live environment reference RE and its out-of-phase electrode. TI's
reference design explains the live-reference approach; this project's simplified
model instead subtracts separately commissioned dry baselines for LEVEL and RL.
It does not claim live environment compensation.
[TI design guide](https://www.ti.com/lit/ug/tidu736a/tidu736a.pdf).

```text
q       = (C_LEVEL - C_LEVEL(dry)) / (C_RL - C_RL(dry))
q_low   = q evaluated from the measured lower-water endpoint pair
q_high  = q evaluated from the measured upper-water endpoint pair
fraction_thousandths = 1000 * (q - q_low) / (q_high - q_low)
```

`0` and `1000` mean the lower and upper measured response endpoints. They are
not millimetres and do not promise linear physical height between those points.
A commissioned supported domain can exclude part of this normalized span.

Measure both dry baselines with the final glass/soldermask/adhesive stack and unchanged
acquisition settings, before wetting either sensing region. RL must remain wet
throughout the accepted operating range. Its measured wet-minus-dry response
normalizes LEVEL response for the installed liquid. No electrode area assumption,
fabricated offset or live RE reading supplies either baseline. Static baseline
drift is a limitation to evaluate during final-unit commissioning; widening
limits does not establish that the model is correct.

Inputs are signed differential counts in units of `2^-19 pF`, with CAPDAC disabled
and the approved gain/offset register configuration. All counts must be strictly
inside `±(15 * 2^19)`, matching the project's driver and the converter's
differential operating limit. This fixed silicon limit is not a commissioned
channel envelope. [TI FDC1004 data sheet, differential mode and measurement conversion](https://www.ti.com/lit/ds/symlink/fdc1004.pdf).

## Calibration record

`CalibrationData` contains all measured coefficients and chosen validity limits;
there is no `Default` or fabricated production example:

- The measured dry LEVEL and RL counts and raw lower/upper endpoint pairs.
- An inclusive absolute count envelope and maximum count slew rate for each
  of LEVEL and RL. Envelopes must be strictly inside the converter limit.
- The expected reference-difference sign and minimum nonzero magnitude.
- A positive rational minimum separation of the two endpoint responses, chosen
  from the measured signal/noise margin.
- The supported normalized `LevelDomain`, within `0..1000`.
- Positive maximum frame age, maximum complete-frame duration, and maximum
  normalized level slew rate. Frame duration cannot exceed the freshness limit.

`Calibration::new(data)` checks the record before it can produce a stage. It
rejects malformed limits, invalid endpoint channels/references, reversed or
collapsed endpoint ratios, and insufficient endpoint separation. These checks
establish arithmetic and configuration consistency, not physical acceptance.
`data()` retains the original record and `endpoint_ratios()` exposes its exact
derived coefficients for diagnostics and a future persisted record.

The final-unit calibration workflow must retain the raw measurement log, known
water positions, sensor/board identity and revision, acquisition configuration,
glass/soldermask/adhesive stack, and the evidence behind every envelope/rate limit.
Those metadata and storage responsibilities belong to the eventual calibration
workflow. Capture both dry baselines with the same dielectric stack. Capture lower/upper
and intermediate points in both directions with RL wet, then validate temperature,
receding film, deposits, adhesive replacement/gaps, hands, cable motion and pump
switching. No such physical evidence exists merely because this code passes.

## Runtime contract

The adapter constructs `RawFrame { channels, sequence, started_at, completed_at }`
only from a complete, successful two-channel driver frame. Incomplete
acquisitions and I²C errors remain invalid readings outside this API. One
`CalibrationStage` instance lives for the boot/session and remains in place
through sensor power or bus recovery.

```text
Calibration::new(data) -> Result<Calibration, CalibrationConfigError>
CalibrationStage::new(calibration, now)
stage.process(now, raw_frame) -> CalibrationResult
```

The result includes `Reading`, the unchanged raw frame, the exact baseline-subtracted ratio on
success, and a detailed `CalibrationError` on failure. Errors include the
offending channel/count, span, timing, domain rational, or slew measurement.
`CalibrationError::fault()` provides the coarse supervisor fault. A valid result
always retains `frame.started_at` as `Reading.observed_at`, so acquisition and
processing delays cannot refresh old data.

Each submission checks:

1. Monotonic caller time, strictly increasing frame sequence, valid ordered
   start/completion times, and no future or overlapping acquisition.
2. Complete-frame duration and age measured from the first conversion's start.
3. Converter range, all absolute envelopes, reference sign/minimum, and the exact
   normalized supported domain.
4. Per-channel and normalized-result slew against the last accepted frame.

Advancing sequence IDs are consumed even for rejected frames. Retrying a rejected
frame later therefore cannot turn it into a fresh acquisition. IDs must not wrap
or reset during sensor recovery; the adapter owns that counter. Call the stage
once per new complete frame, then preserve the returned reading between control
ticks. The supervisor performs its usual age check on those intervening ticks.
Future or backwards timestamps are errors, not values to repair.

The exact output rational is checked against the supported domain before nearest
integer rounding. A fraction slightly below zero or above the accepted maximum
is invalid even if it would round to an allowed integer. Nothing is clamped into
valid LOW or HIGH.

Slew uses elapsed time between acquisition starts. Raw limits use counts/second;
the output limit uses the rounded controller fraction in thousandths/second.
Measured limits must account for sequential-channel skew and acquisition timing
variation within the bounded frame duration. The first accepted frame has no
movement history to compare. Invalid frames do not erase the last accepted slew
anchor, so an impossible jump does not become a valid new baseline on the next
sample. A sufficiently long observation gap can permit a larger physical change;
the supervisor still requires its normal recovery behavior. This is a plausibility
check, not evidence about unseen motion.

Changing calibration requires constructing a validated replacement stage as an
explicit commissioning/configuration operation while control is held off. Do not
recreate the stage on a fault to discard its history. The app must coordinate
configuration persistence and reset water-notification confirmation/baselines
when the calibration changes. Missing or unaccepted calibration remains
`Reading::Invalid(Fault::Uncalibrated)`.

## Arithmetic and verification

No floating point, allocation or external arithmetic dependency is used. The
strict converter bounds make every numerator difference and positive denominator
smaller than `2^24`. Endpoint cross-differences are smaller than `2^49`; the
normalized numerator product is smaller than `2^83` and its denominator smaller
than `2^73`. Signed `i128` therefore holds normalization and domain comparisons,
including rounding, with ample margin. Denominator positivity and endpoint order
are established before division. Slew products use `u128`; their largest operand
product is a `u32` rate times `u64` elapsed time, below `2^96`.

Host tests cover nonzero baseline arithmetic with changing reference spans,
negative calibrated polarity, converter extrema, malformed settings, collapsed
or reversed references, all channel envelopes, exact domain rejection before
rounding, stale/replayed/future/backwards/overlapping frames, frame duration, raw
and normalized slew, retained history after invalid frames, and water-transition
confirmation after an invalid frame. Test measurements are explicitly synthetic.

Run from `firmware/`: `cargo fmt --check`,
`cargo clippy --locked --all-targets -- -D warnings`, and `cargo test --locked`.
This verifies the calculation and rejection behavior. It cannot establish that
RL is wet, stored dry baselines remain representative, geometry is suitable, or the glass/adhesive system needs no
routine cleaning. See the [sensor design basis](sensor-design-basis.md) for those
physical assumptions and acceptance checks.

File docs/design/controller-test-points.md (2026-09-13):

# Controller test and UART service pads

The test-point electrical/mask contract remains applicable. Numeric placement
and enclosure positions below are historical; current source datums are in
[controller placement](controller-placement.md) for the 150 × 110 mm top board.

Status: connected source section, 2026-09-12. The pad bank implements the
[controller design basis](controller-design-basis.md) observability and UART
service requirements. It now shares the complete source placement within the
70 x 110 mm controller board; enclosure access and routing remain under review.

## Electrical assignment

Each reference has one electrical pad numbered 1. Ground is the isolated
controller ground. `RELAY_GATED` is the AND-gate output before the MOSFET gate
resistor; observing it does not establish coil current or relay-contact state.

| Reference | Net | Silkscreen | Intended observation |
| --- | --- | --- | --- |
| TP1 | GND | GND | Return beside supply measurements |
| TP2 | V5_PSU | 5V PSU | Protected PSU secondary and coil supply |
| TP3 | V5_LOGIC | 5V LOGIC | Diode-OR output, below its source by a diode drop |
| TP4 | V3V3 | 3V3 | Controller regulator output |
| TP5 | SENSOR_SDA | SDA | Controller-side I2C data |
| TP6 | SENSOR_SCL | SCL | Controller-side I2C clock |
| TP7 | PSU_GOOD | PSU GOOD | Independent PSU qualification |
| TP8 | RELAY_GATED | RELAY EN | Hardware-qualified relay command |
| TP9 | UART0_RX | RX 3V3 | Module pad 24, GPIO17, UART receive |
| TP10 | UART0_TX | TX 3V3 | Module pad 25, GPIO16, UART transmit |
| TP11 | GND | GND | Return beside UART service pads |

UART pads carry **3.3 V logic**. Connect an external adapter TX to TP9, RX to TP10
and ground to TP11; leave the adapter's supply output disconnected. The pads do
not provide USB or 5 V service power. Power the controller through its normal
isolated PSU or the separate protected service connector J2. USB VBUS remains a
presence/reference input under the self-powered USB contract. No installed UART
bridge or populated service header is required.

## Source-owned geometry

The board-owned footprint is
`CrystalShim:TestPoint_Pad_D2.0mm_NoPaste`. It is one top-side circular copper pad,
2.00 mm diameter, centered on the component origin. An explicit 0.05 mm mask
expansion produces a 2.10 mm opening. It has no hole and no solder-paste aperture.
These dimensions are a project probe-access choice, not a manufacturer's land
pattern for a purchased component.

A 4 mm diameter courtyard reserves local probe access. Pad centers are at least
8 mm apart, leaving 6 mm between copper edges. Keep component bodies, connectors,
cable overhang and enclosure obstructions outside each probe-access circle in
the final integrated placement. Ref and short signal labels sit 2.2 mm above and
below pad center at 0.8 mm text size. Their nearest text bounds remain outside
the mask opening; final silkscreen and access checks still belong to layout.

All coordinates below are millimetres, measured from the board center with X
right and Y up. Convert to upper-left X-right/Y-down by `(35 + X, 55 - Y)`.

| References | Center X | Center Y |
| --- | --- | --- |
| TP1, TP2, TP3, TP4 | -30.5, -18, -10, -2 | -10 |
| TP5, TP6, TP7, TP8 | -26, -18, -10, -2 | -18 |
| TP9, TP10, TP11 | 15 | -13, -21, -5 respectively |

This lower-half allocation stays inside the 70 x 110 mm outline and away from
the four mounting-hole reserves. It passes the complete source courtyard check
and retains the 8 mm minimum centre spacing; enclosure access and final routing
still need verification. Keep
I2C and relay measurement branches short when integrating it. The UART locations
are individual probe/solder pads, not a claim of compatibility with a header or
pogo connector pitch.

## BOM and initial export

These eleven unpopulated copper features add no purchased BOM line, MPN or
supplier quantity. Source uses the dedicated test-point component type. Native
footprints exclude them from BOM and component-position files; native schematic
instances retain `on_board` and exclude them from BOM. The schematic uses a
single passive pin and an actual electrical net label for each pad.

The pinned converter adds `F.Paste` to exposed SMD pads despite the source's
zero-paste setting. Complete initial export must call
`omitTestPointPasteForInitialExport(board)` from
[test-points.tsx](../../pcb/controller/design/test-points.tsx) on the generated
`KicadPcb` object before its first stage serialization. It validates the complete
TP1-TP11 bank, pad number, net, copper, mask margin, layers and exclusions before
removing only `F.Paste`. It rejects unexpected or already-adjusted targets and
preserves unrelated objects. It never reads or edits an existing native board.

The custom test-point symbol preserves the explicit BOM metadata that the
pinned built-in symbol path drops. Each fixed reference has a distinct symbol
name because the resolved reference text affects symbol bounds. Reusing TP1's
symbol for TP10/TP11 had produced incorrect native pin origins; unique symbols
preserve both visible references and native connectivity. This does not alter
the shared schematic exporter.

## Verification and remaining integration

Focused source tests check the exact eleven net assignments, real schematic
reachability, exposed copper/mask, zero source paste, probe spacing and absence
of purchased-part metadata. Initial-converter tests check native copper/origin,
mask, pin/net and BOM/CPL parity, fail-before-mutation behavior, unrelated-object
preservation and unique schematic symbol identities.

Disposable KiCad 10.0.5 readback verified all eleven schematic pins and all eleven
physical pads, a 2.00 mm copper diameter, a 2.10 mm mask opening, zero paste pads
and eleven BOM/CPL exclusions. Source schematic, source copper and native
schematic renders were visually inspected. Scratch evidence is in
`/tmp/crystal-shim-test-points`, with `native-proof.json` and `verify-native.py`.
The parent capture must integrate this section, invoke the initial-only paste
adjustment, and declare the corresponding final native footprint/augmentation.
Full-board routing, DRC, physical probe access and fabrication remain pending.

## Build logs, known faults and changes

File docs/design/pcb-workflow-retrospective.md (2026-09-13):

# PCB workflow retrospective

Date: 2026-09-13. Scope: the visual design, compact three-board ECO, native
routing preparation and the tooling work that followed it. This records process
lessons, not a new electrical design or fabrication approval.

## The main correction

We should have agreed on the physical product before spending substantial effort
on placement. The first sensor layout did not express the intended tall, slim
strip. A visual target made the mounting, orientation and wire exit clear much
faster than discussing a populated PCB in isolation.

The useful sequence is now: visual agreement, dimensional contract, source and
native change plan, checked application, complete preparation audit, visual and
electrical review, then one final acceptance. The instructions and
[workflow commands](../../pcb/tools/README.md) encode that sequence. They do not
turn an attractive render into evidence that a circuit will work.

## What worked

- **Visual agreement resolved real requirements.** The sensor became an
  18 × 64 mm adhesive strip entirely below the rim, with its pigtail exiting
  left. The controller and mains became a common 150 × 110 mm stack with aligned
  M3 mounting holes. These decisions are now in canonical mechanical and board
  specifications, with the reference images retained.
- **The source/native ownership split protected routing work.** Tscircuit owns
  circuit intent, parts, board specification and placement. Native KiCad owns
  routes and declared augmentations. Explicit ECO plans and before/after checks
  made it possible to change placement without treating a fresh export as a
  substitute for the adopted board.
- **Actual native checks found problems that source checks could not.** Plane
  fills, USB pair settings, narrow pad escapes, paste openings, internal sensor
  pads, manufacturing metadata and native exclusions all needed saved-project
  inspection. A source test pass was useful evidence, but insufficient by itself.
- **Bounded adversarial reviews were useful.** Reviewing concrete geometry,
  interfaces and verification logic caught omissions without reopening the
  agreed architecture or adding components. A narrow review with a specific
  failure question was more useful than another broad design discussion.
- **Explicit distinctions prevented false completion claims.** Placement
  acceptance, preparation for routing, routed-board fabrication checks and
  physical commissioning remain separate. Unconnected counts are expected at
  this handoff; physical calibration, EMI and thermal performance are unmeasured.

## What cost unnecessary effort

| Friction | What happened | Why it was inefficient | What changes now |
| --- | --- | --- | --- |
| Physical design started late | Board shape and component placement preceded a clear visual agreement | Rework crossed specifications, source, native placement and evidence | Establish the image and exact dimensional contract first |
| GUI used to discover capabilities | Stack settings, custom-rule installation and schematic properties needed UI work | Repeated navigation, focus, clipboard and save operations gave weak machine-readable feedback | Run capability discovery first; use verified helpers where supported |
| Tool success did not mean the requested field changed | Konnect single-component field edits could return success without processing fields | Repeated attempts and manual inspection were needed to find silent failure | Guarded batch replacement, exact semantic comparison and native netlist verification |
| Annotation was mistaken for replacement | Adding an MPN annotation could create another property with the same name | The file then needed cleanup and another authoritative save | Reject duplicate properties and replace existing fields only |
| Native operations lacked a shared lifecycle | Project attachment, fills, saves, UUID selection and readback appeared in task scripts | Each script rediscovered API behavior and could miss a preservation check | A shared project loader and declarative transaction engine |
| Preparation checks came late | Paste, stencil/process details, labels and routing settings were completed in several passes | Each late change could invalidate earlier evidence and require another ECO acceptance | Put the full preparation profile beside the change plan and audit it before acceptance |
| Too many documents carried the same decision | Temporary targets, canonical specs and downstream evidence overlapped | It became harder to tell which statement governed implementation | Images remain references; exact requirements live in canonical documents |
| Evidence was copied repeatedly | Full snapshots and command output appeared in successive evidence directories | Large diffs obscured which inputs were actually validated | Content-addressed evidence objects with a small run index and explicit hashes |
| Tool warnings had ambiguous significance | Source geometry heuristics and native DRC did not model every object the same way | A nonzero status could mean a real placement problem or an inapplicable body model | Preserve the raw finding, bind narrow exceptions exactly and require an independent relevant check |

## Confirmed tool defects and limits

The field-edit behavior was reproduced on a temporary copy of the real sensor
schematic using installed Konnect 0.2.1 and KiCad 10.0.5. Its single-component
editor advertises `fields` but does not process them. Annotation appends instead
of replacing. The batch editor replaces existing fields, but can partially apply
a request and mishandle quote characters. See the pinned source links in the
[Konnect skill](../../.agents/skills/konnect/SKILL.md).

`kicad_schematic.py` now runs that batch tool on a temporary copy, verifies the
entire semantic tree and native net connectivity, rechecks the original hash,
then publishes the verified bytes. Missing fields, duplicate properties,
unsupported characters, partial success and unrelated changes fail before
publication. It requires the actual leaf sheet containing the component.
Reference changes, new fields and symbol exclusion flags are outside this
wrapper's supported subset.

Physical stack serialization and custom-rule installation still have no verified
native writer in this installed toolchain. KiCad's SWIG stack descriptor is
opaque; enabling copper layers is a different operation from setting dielectric
materials and thickness. The inspected Konnect rule-writing operations target
legacy or invalid locations. The CLI can validate the installed adjacent rule
file. For these remaining writes, the documented KiCad GUI procedure remains the
fallback, followed by saved-state verification. This is a known capability gap,
not a reason to try arbitrary protected-file edits.

Testing the new helpers found another source of false confidence: the native
board API's connected-track-width setting is an in-memory value, while the GUI
stores its session choice separately in `.kicad_prl`. Loading and saving the
board did not prove that preference persisted. The engine therefore does not
advertise a router-preference writer. Preparation checks verify the configured
netclasses and rule sizes, and report available GUI preference facts separately.

The sensor's source placement checker also treats the multilayer, copper-only E1
footprint as a top-side connector body. It reports 15 apparent body intrusions,
while its placement DRC reports zero errors and warnings. The workflow records
the original nonzero result and accepts only its exact command/output identity
as a documented checker limitation. Native copper DRC and the preparation audit
must still pass. A changed output requires investigation, rather than silently
inheriting a broad E1 exemption.

## Reusable implementation

| Tool | Responsibility | Deliberate boundary |
| --- | --- | --- |
| `pcb_workflow.py` | Begin, plan, draft simple placement transactions, apply, validate, record review and accept; bind evidence to current inputs | Existing-board ECOs; initial export still uses the established handoff tools |
| `kicad_native.py` | Load the adjacent project, apply explicit UUID-bound operations on a copy, refill, save, reopen and verify before publishing | Supported native operations only; native application is not electrical acceptance |
| `kicad_schematic.py` | Verified replacement of existing leaf-sheet properties through Konnect | No schematic regeneration, net rewiring or new-symbol authoring |
| `pcb_readiness.py` | Audit actual geometry, stack, planes, vias, rules, routing settings, paste, labels and exact exclusions | Preparation for routing, not final connectivity or physical commissioning |
| `tscircuit_handoff.py` | Existing source/native parity, preservation and accepted-lock advancement | Retained compatibility; used by the new lifecycle rather than duplicated |

The native transaction engine handles explicit footprint moves and associated
copper, pad paste settings, supported fields, tracks, through vias, simple zones,
rectangular outlines, board text and supported routing settings. It does not infer
which copper belongs to a moved footprint. The transaction must name those
objects. More complex electrode or footprint replacement still needs a
source-aware identity mapping and review.

Publication across board and project files is not a single atomic filesystem
operation. The engine uses editor checks, input hashes, a transaction lock and
guarded rollback. Known concurrent changes cause failure; an external writer can
still race the last check, so mutation requires the project to be closed.
Read-only auditing can inspect saved bytes while the GUI remains open, but cannot
see unsaved editor changes.

The old `apply_routing_guardrails.py` one-off writer is retired. Its fixed
historical evidence paths and direct publication were not a suitable reusable
entry point for the current compact boards.

## How the next board change should run

1. Agree on the visible form and record exact size, holes, glass/rim reference,
   connector exits, stack access and mounting in the canonical specification.
2. Read the capability report and complete the preparation profile before
   deciding how to apply the change. Identify actual unsupported operations early.
3. Capture the accepted baseline, update source and declarations, then generate
   the full ECO plan. Resolve identity and attached-copper questions before writes.
4. Apply supported changes through checked native transactions and guarded
   schematic batches. Use the verified GUI fallback only for remaining gaps.
5. Run source checks, strict ERC and schematic parity, native DRC, the complete
   preparation audit and separate copper/mask/paste/silk/fabrication-layer renders.
6. Review the actual renders and reports against the agreed contract. Record
   concrete findings, resolve them and advance the accepted lock once.
7. Route using the existing routing guide, then run the final connectivity and
   manufacturing checks. Revalidate whenever the relevant saved inputs change.

This removes repeated setup scripts and silent-success guesses. It does not
eliminate the need for engineering judgment, native visual inspection or the
final physical commissioning tests. Shared helpers and procedures are synced to
Stillair; each project retains its own board profiles and acceptance evidence.

The [tooling validation receipt](evidence/pcb-workflow/validation.json) records
the full project check, focused test results, all three saved-board audits,
actual mutation/rejection tests on board copies and the temporary-copy acceptance
rehearsal. The accepted product native files and comparison locks were preserved.

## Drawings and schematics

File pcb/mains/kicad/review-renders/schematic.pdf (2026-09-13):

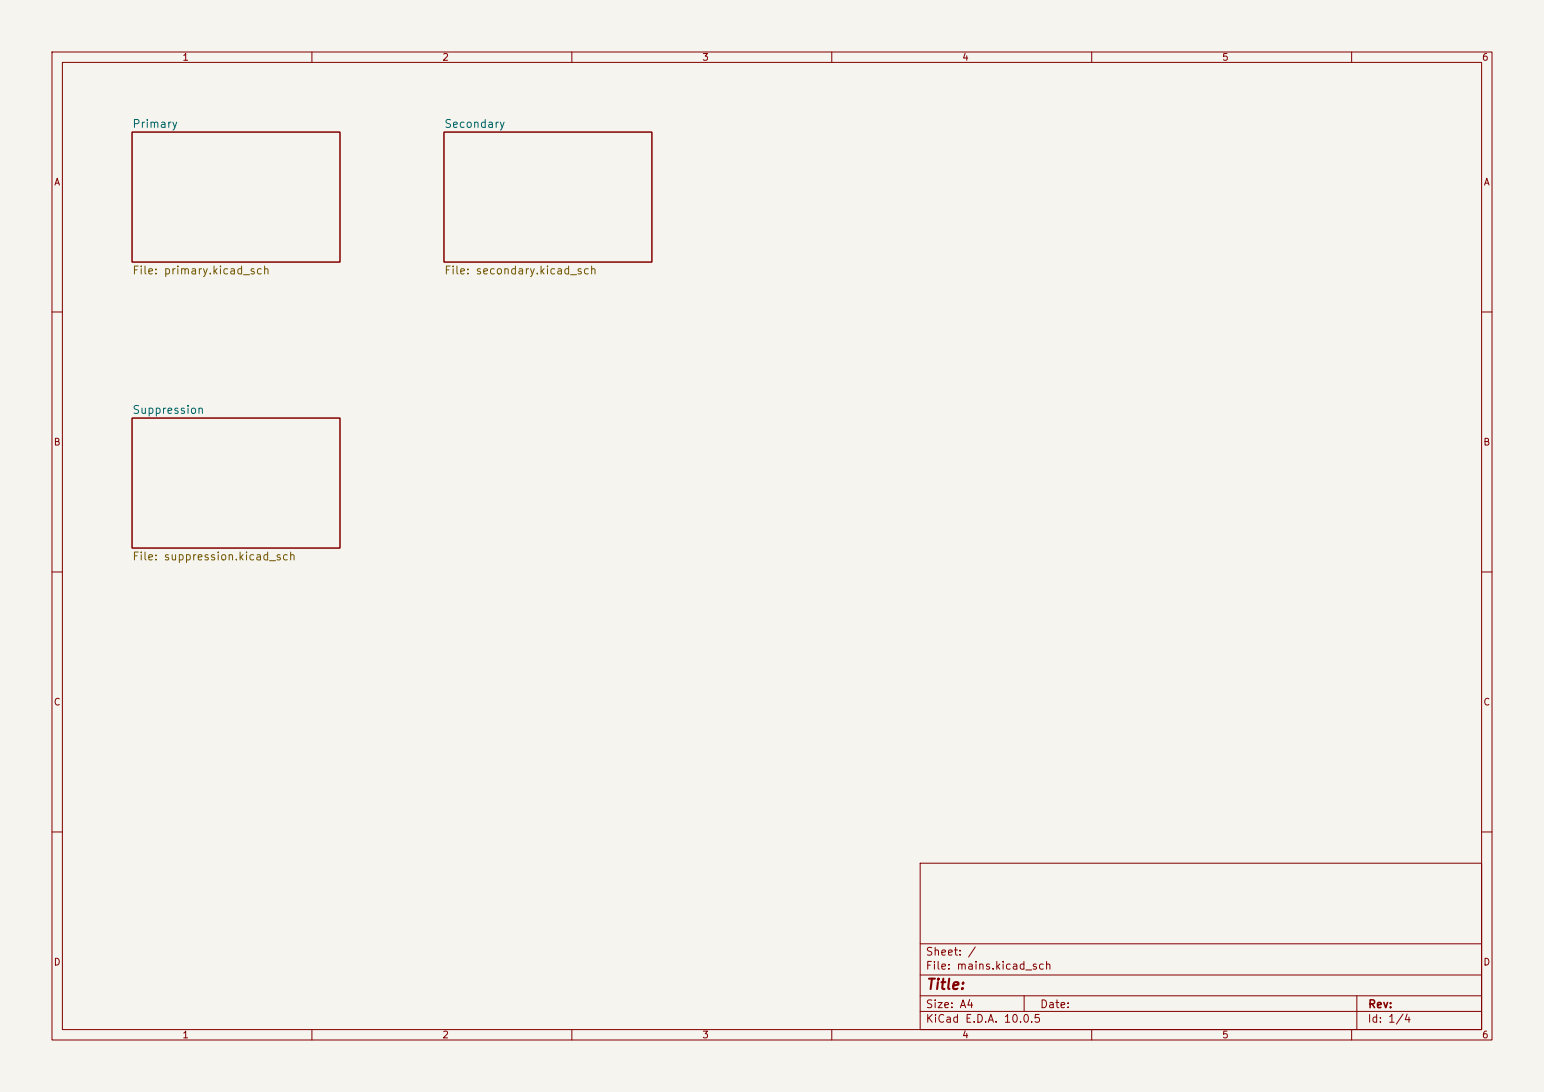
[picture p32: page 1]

Size: A4 | Rev:
KiCad E.D.A. 10.0.5 | Id: 1/4

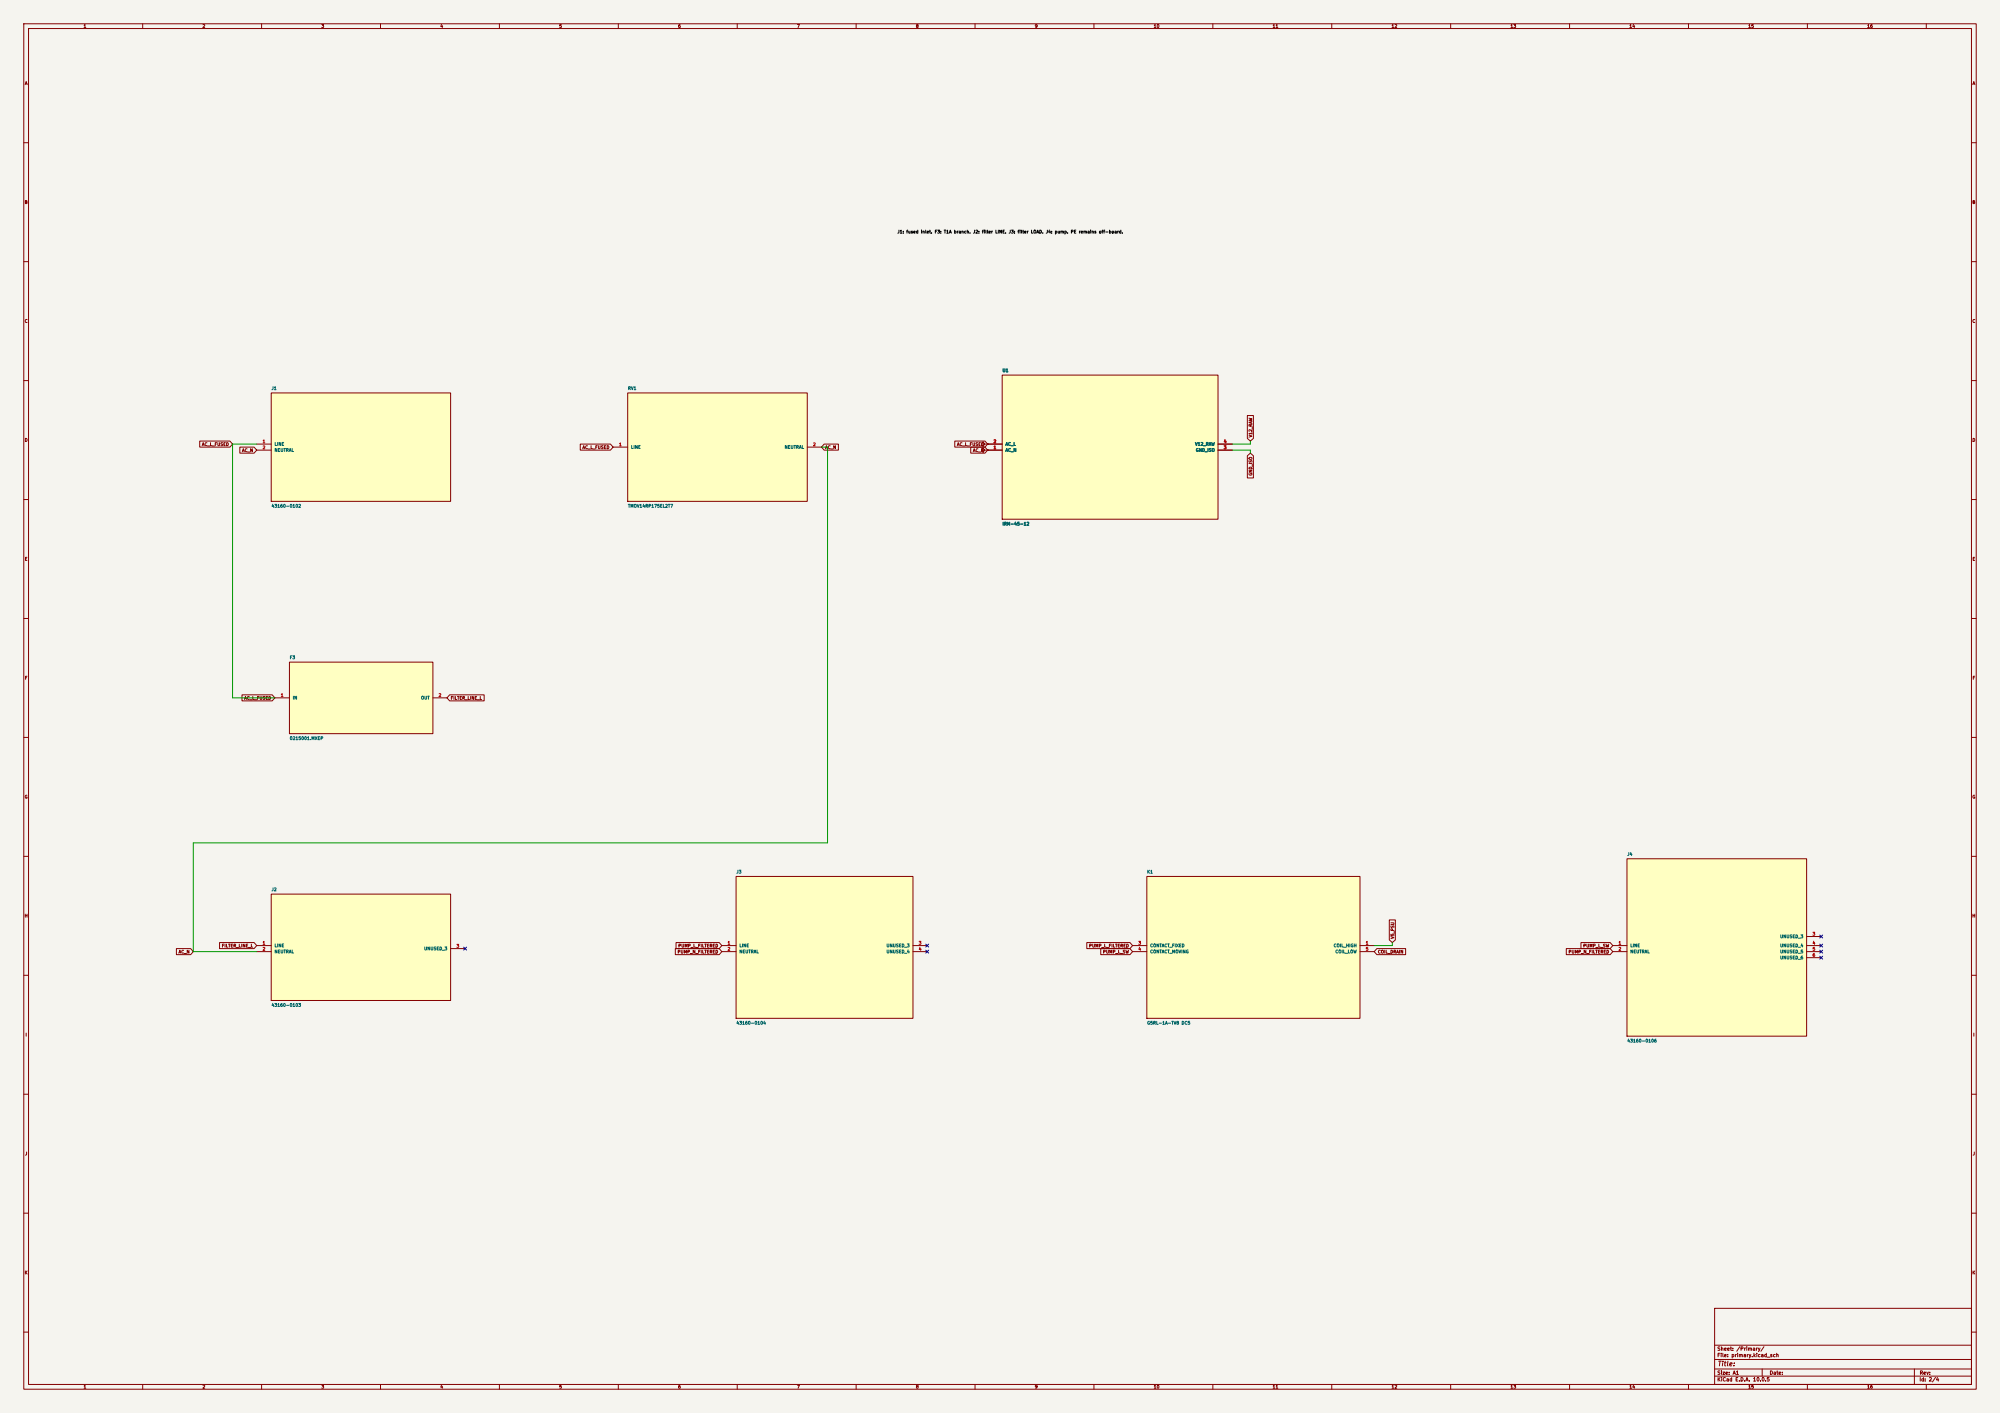
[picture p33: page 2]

J1: fused inlet. F3: T1A branch. J2: filter LINE. J3: filter LOAD. J4: pump. PE remains off-board. U1

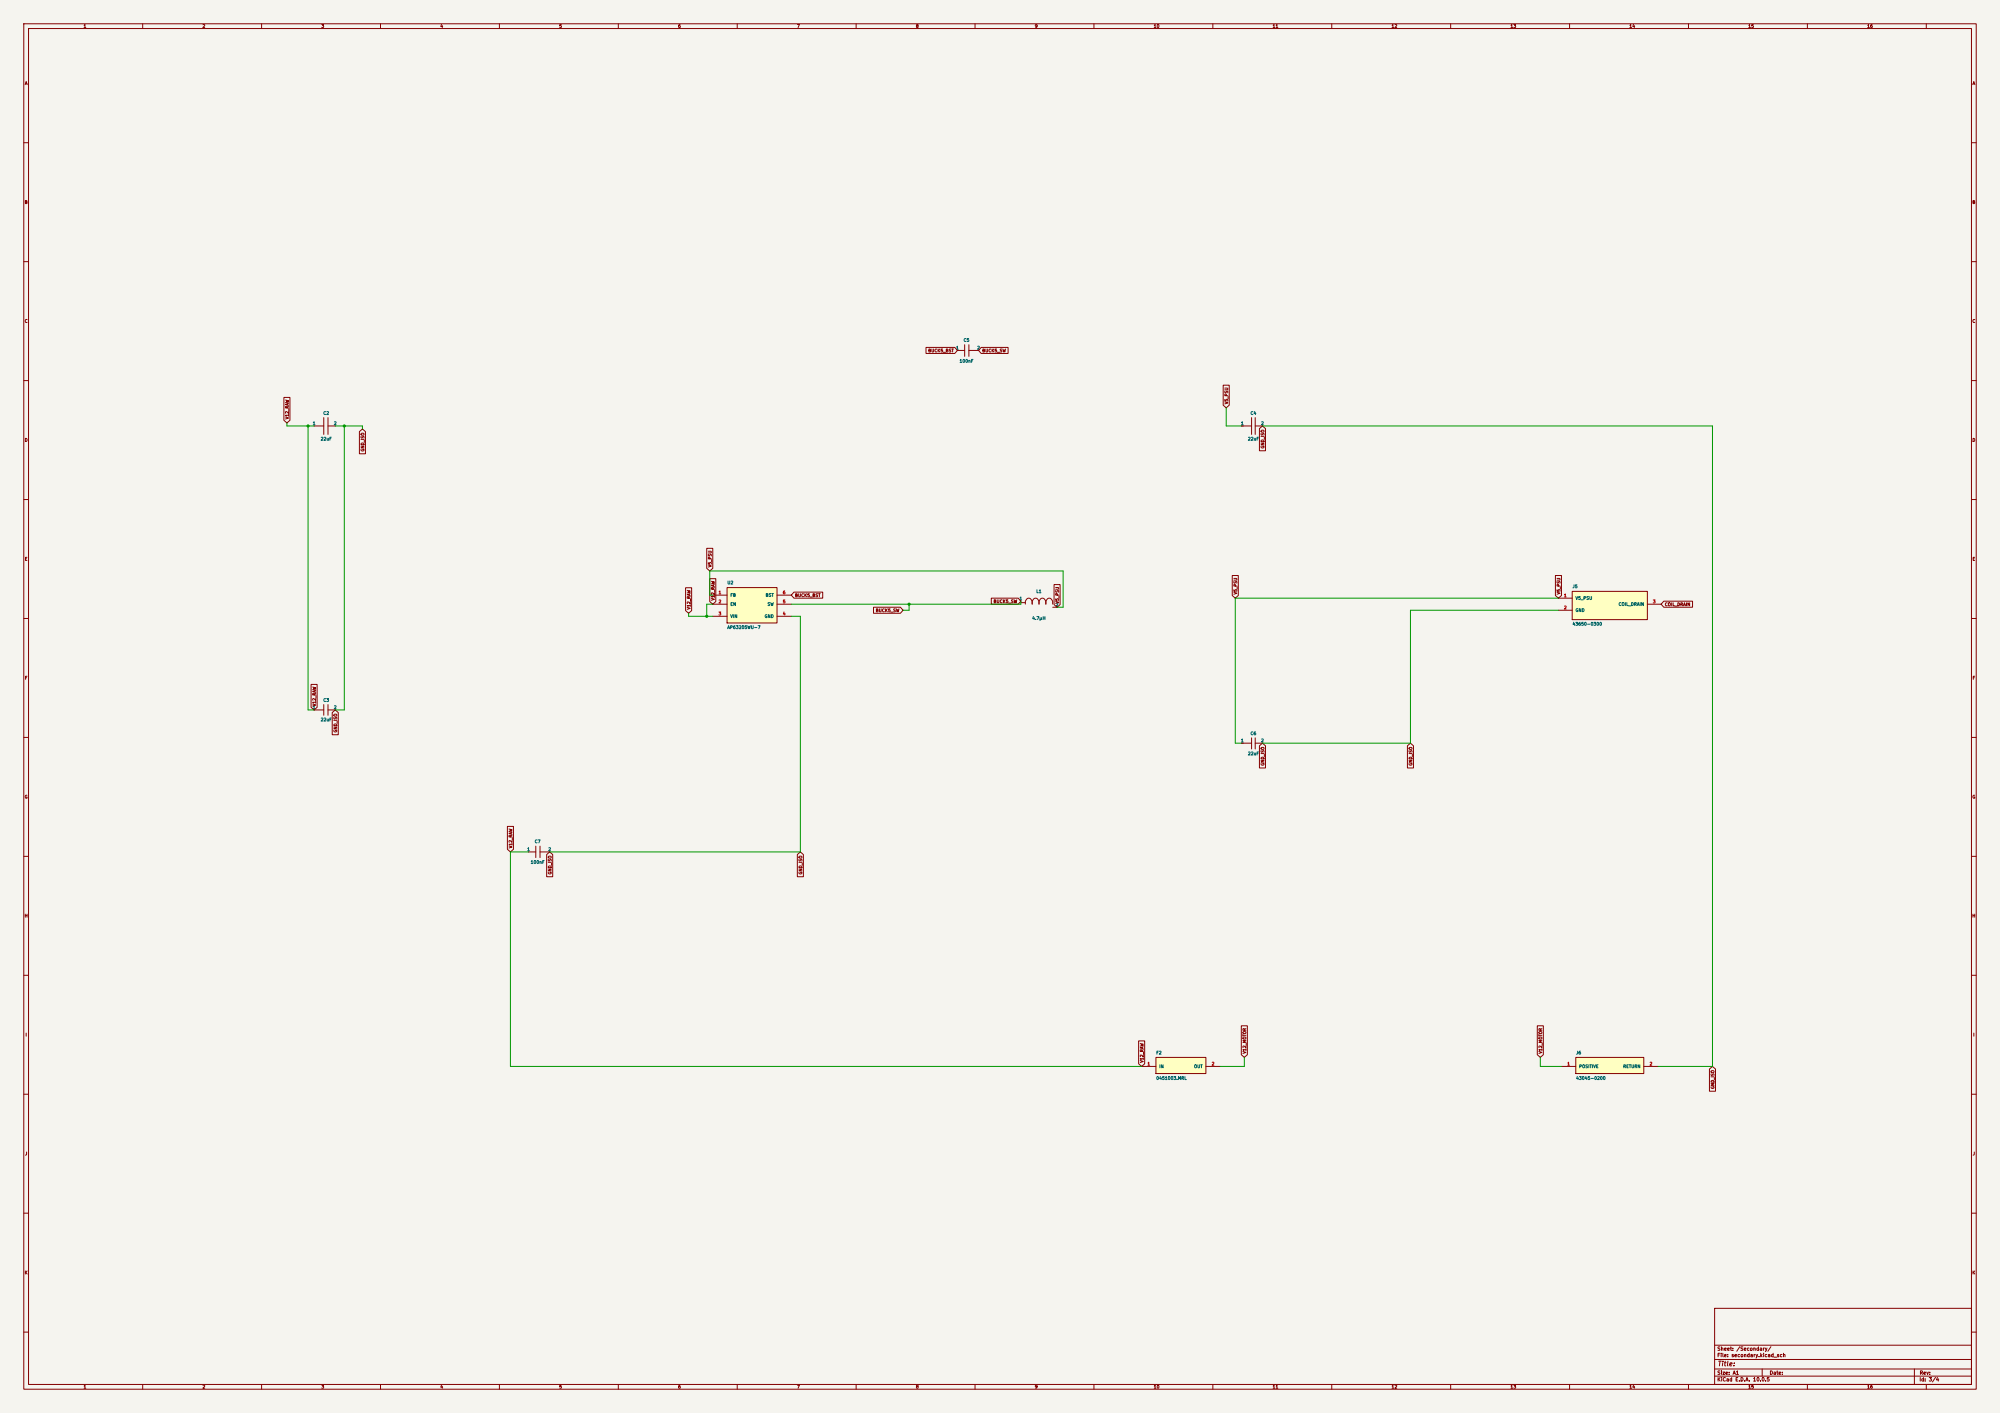
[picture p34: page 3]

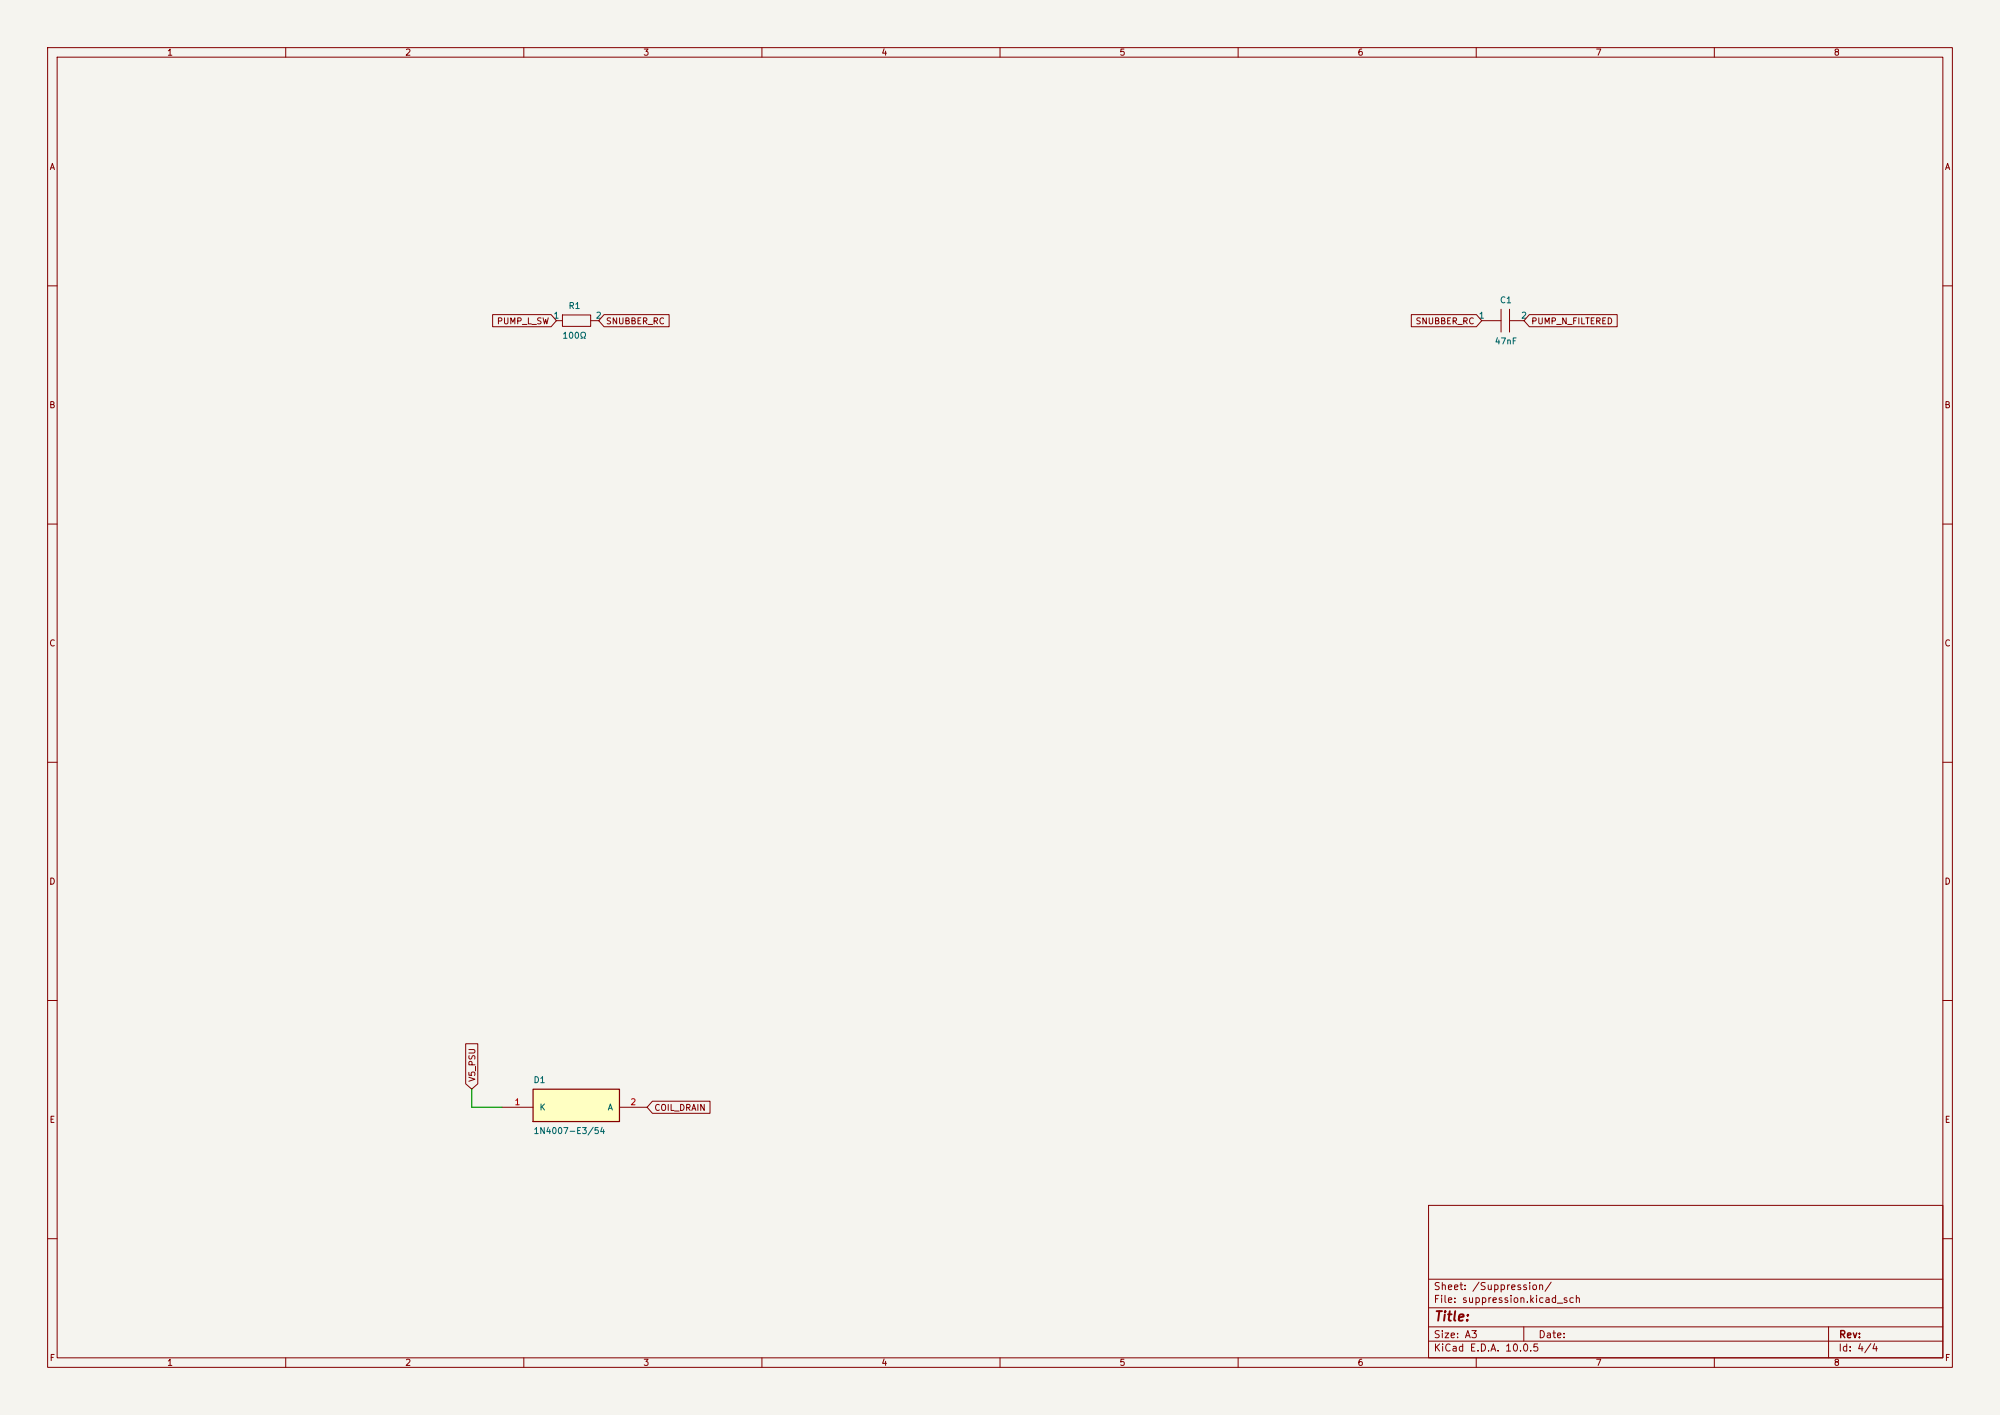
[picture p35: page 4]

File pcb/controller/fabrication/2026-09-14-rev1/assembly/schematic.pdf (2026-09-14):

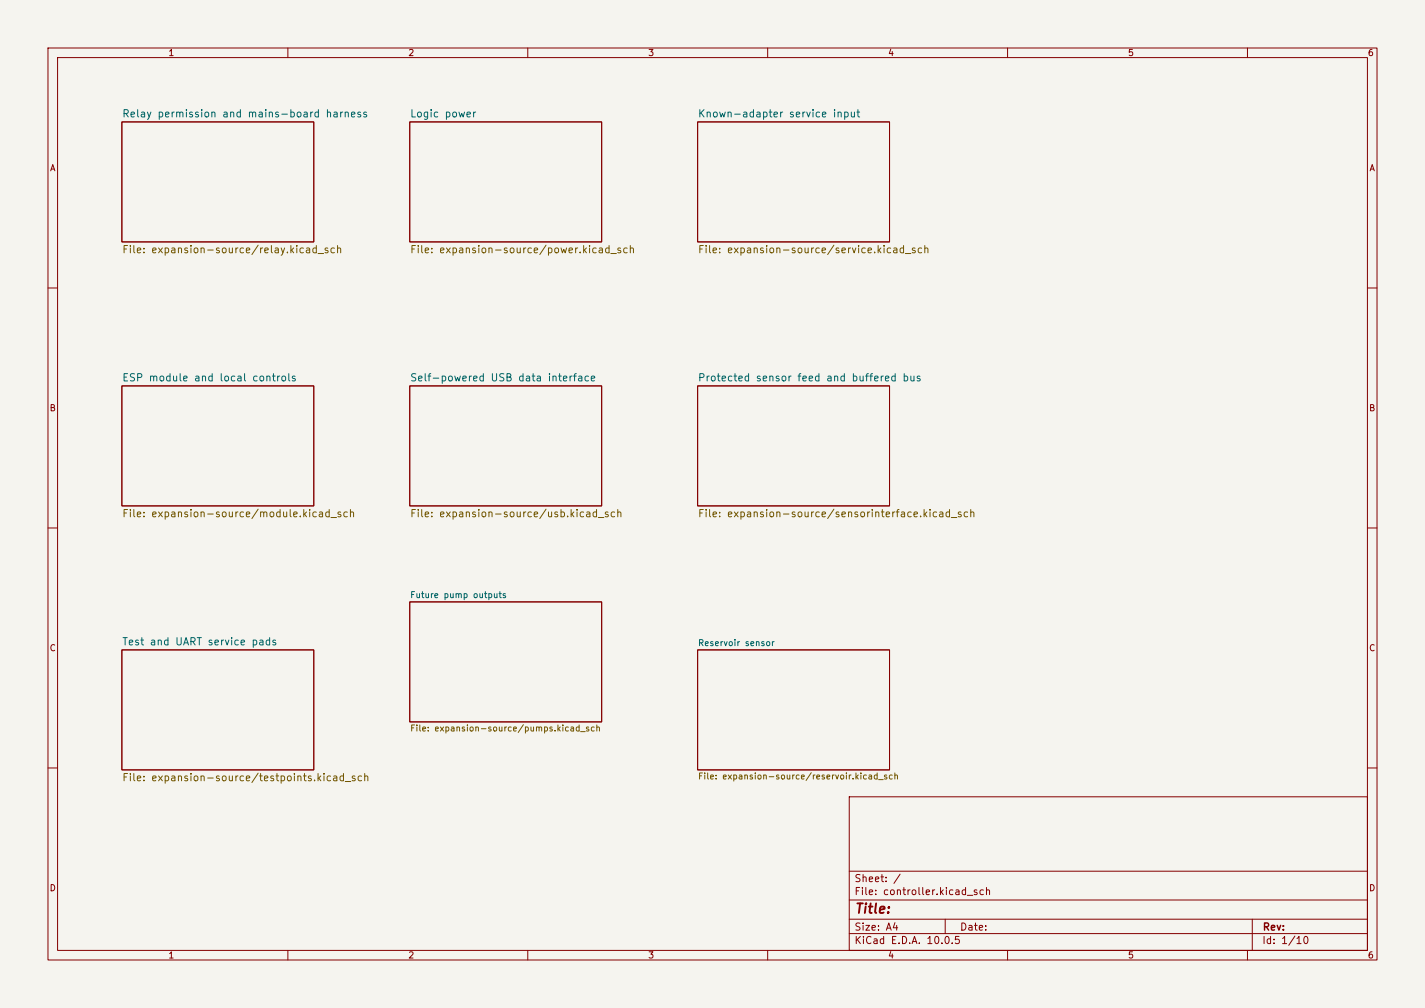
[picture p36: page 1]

Relay permission and mains-board harness

Known-adapter service input

File: expansion-source/relay.kicad_sch

File: expansion-source/power.kicad_sch

File: expansion-source/service.kicad_sch

ESP module and local controls

Self-powered USB data interface

Protected sensor feed and buffered bus

File: expansion-source/module.kicad_sch

File: expansion-source/usb.kicad_sch

File: expansion-source/sensorinterface.kicad_sch

Future pump outputs File: expansion-source/pumps.kicad_sch

Test and UART service pads

Reservoir sensor File: expansion-source/reservoir.kicad_sch

File: expansion-source/testpoints.kicad_sch

Size: A4 | Rev:
KiCad E.D.A. 10.0.5 | Id: 1/10

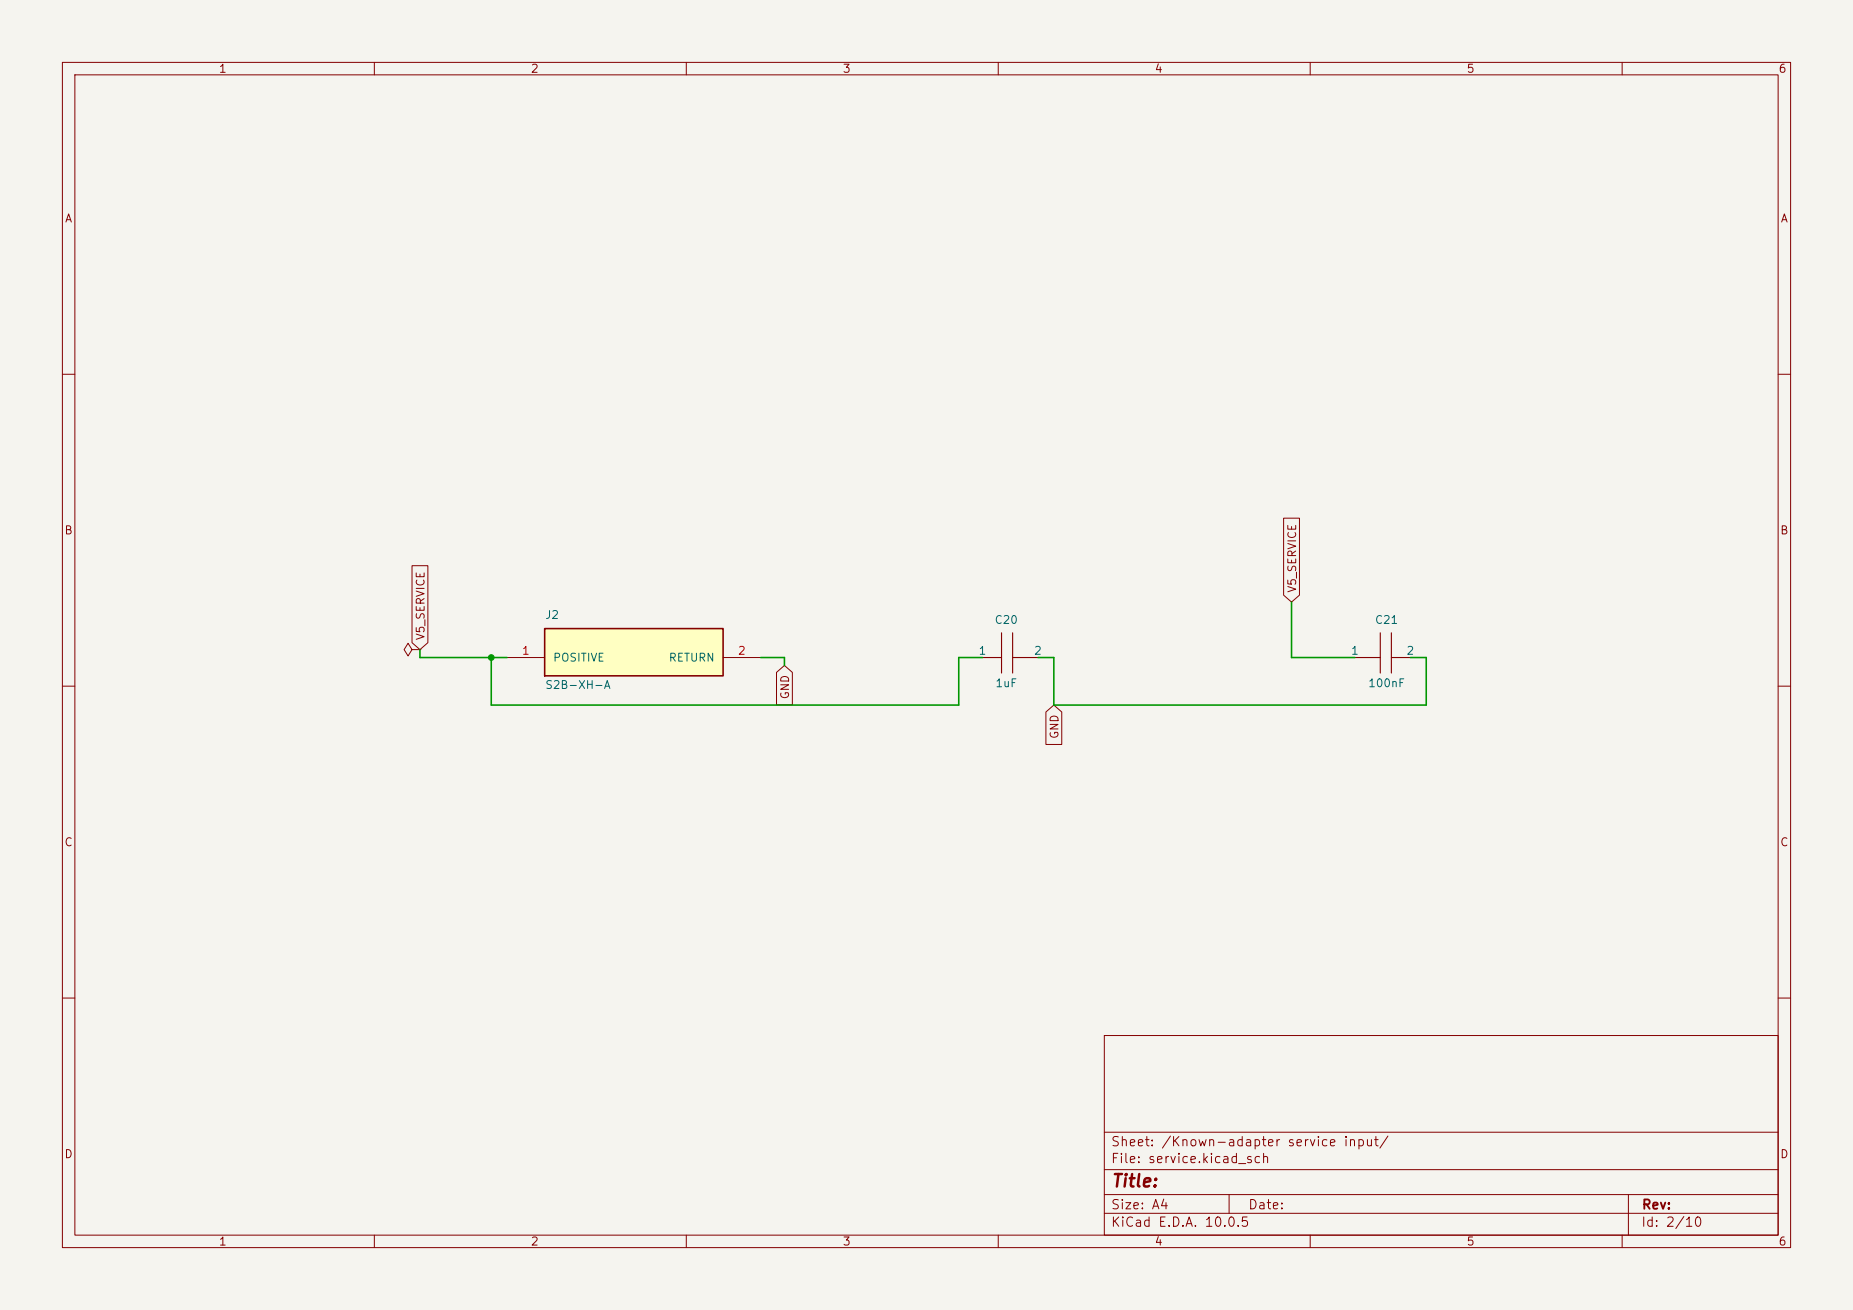
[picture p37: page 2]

Sheet: /Known-adapter service input/
File: service.kicad_sch
Title:

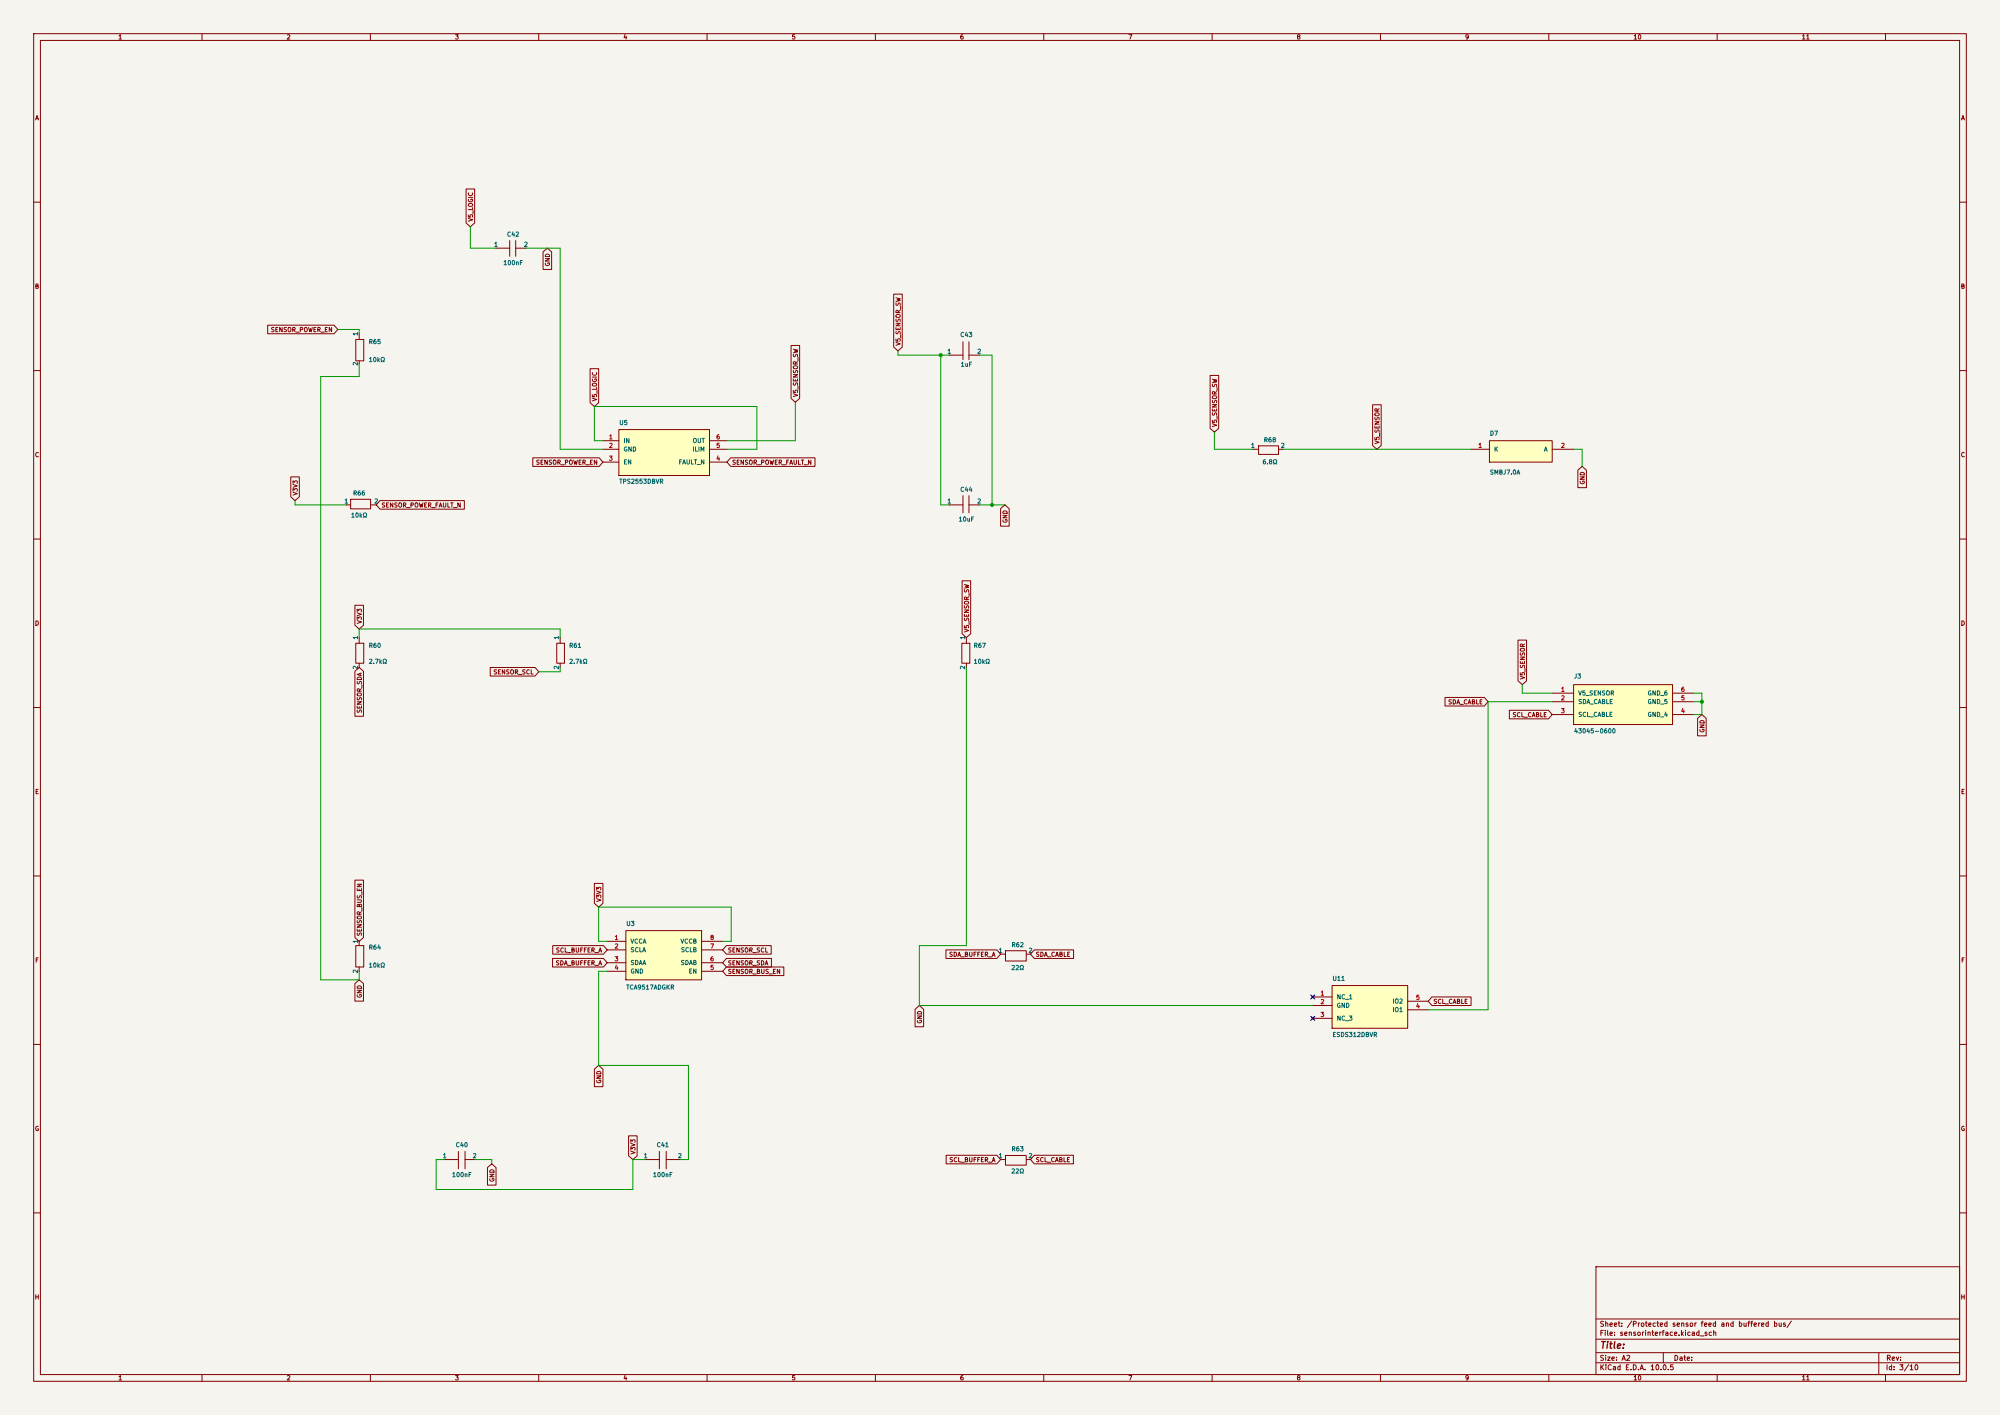
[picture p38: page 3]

Sheet: /Protected sensor feed and buffered bus/
File: sensorinterface.kicad_sch
Title:

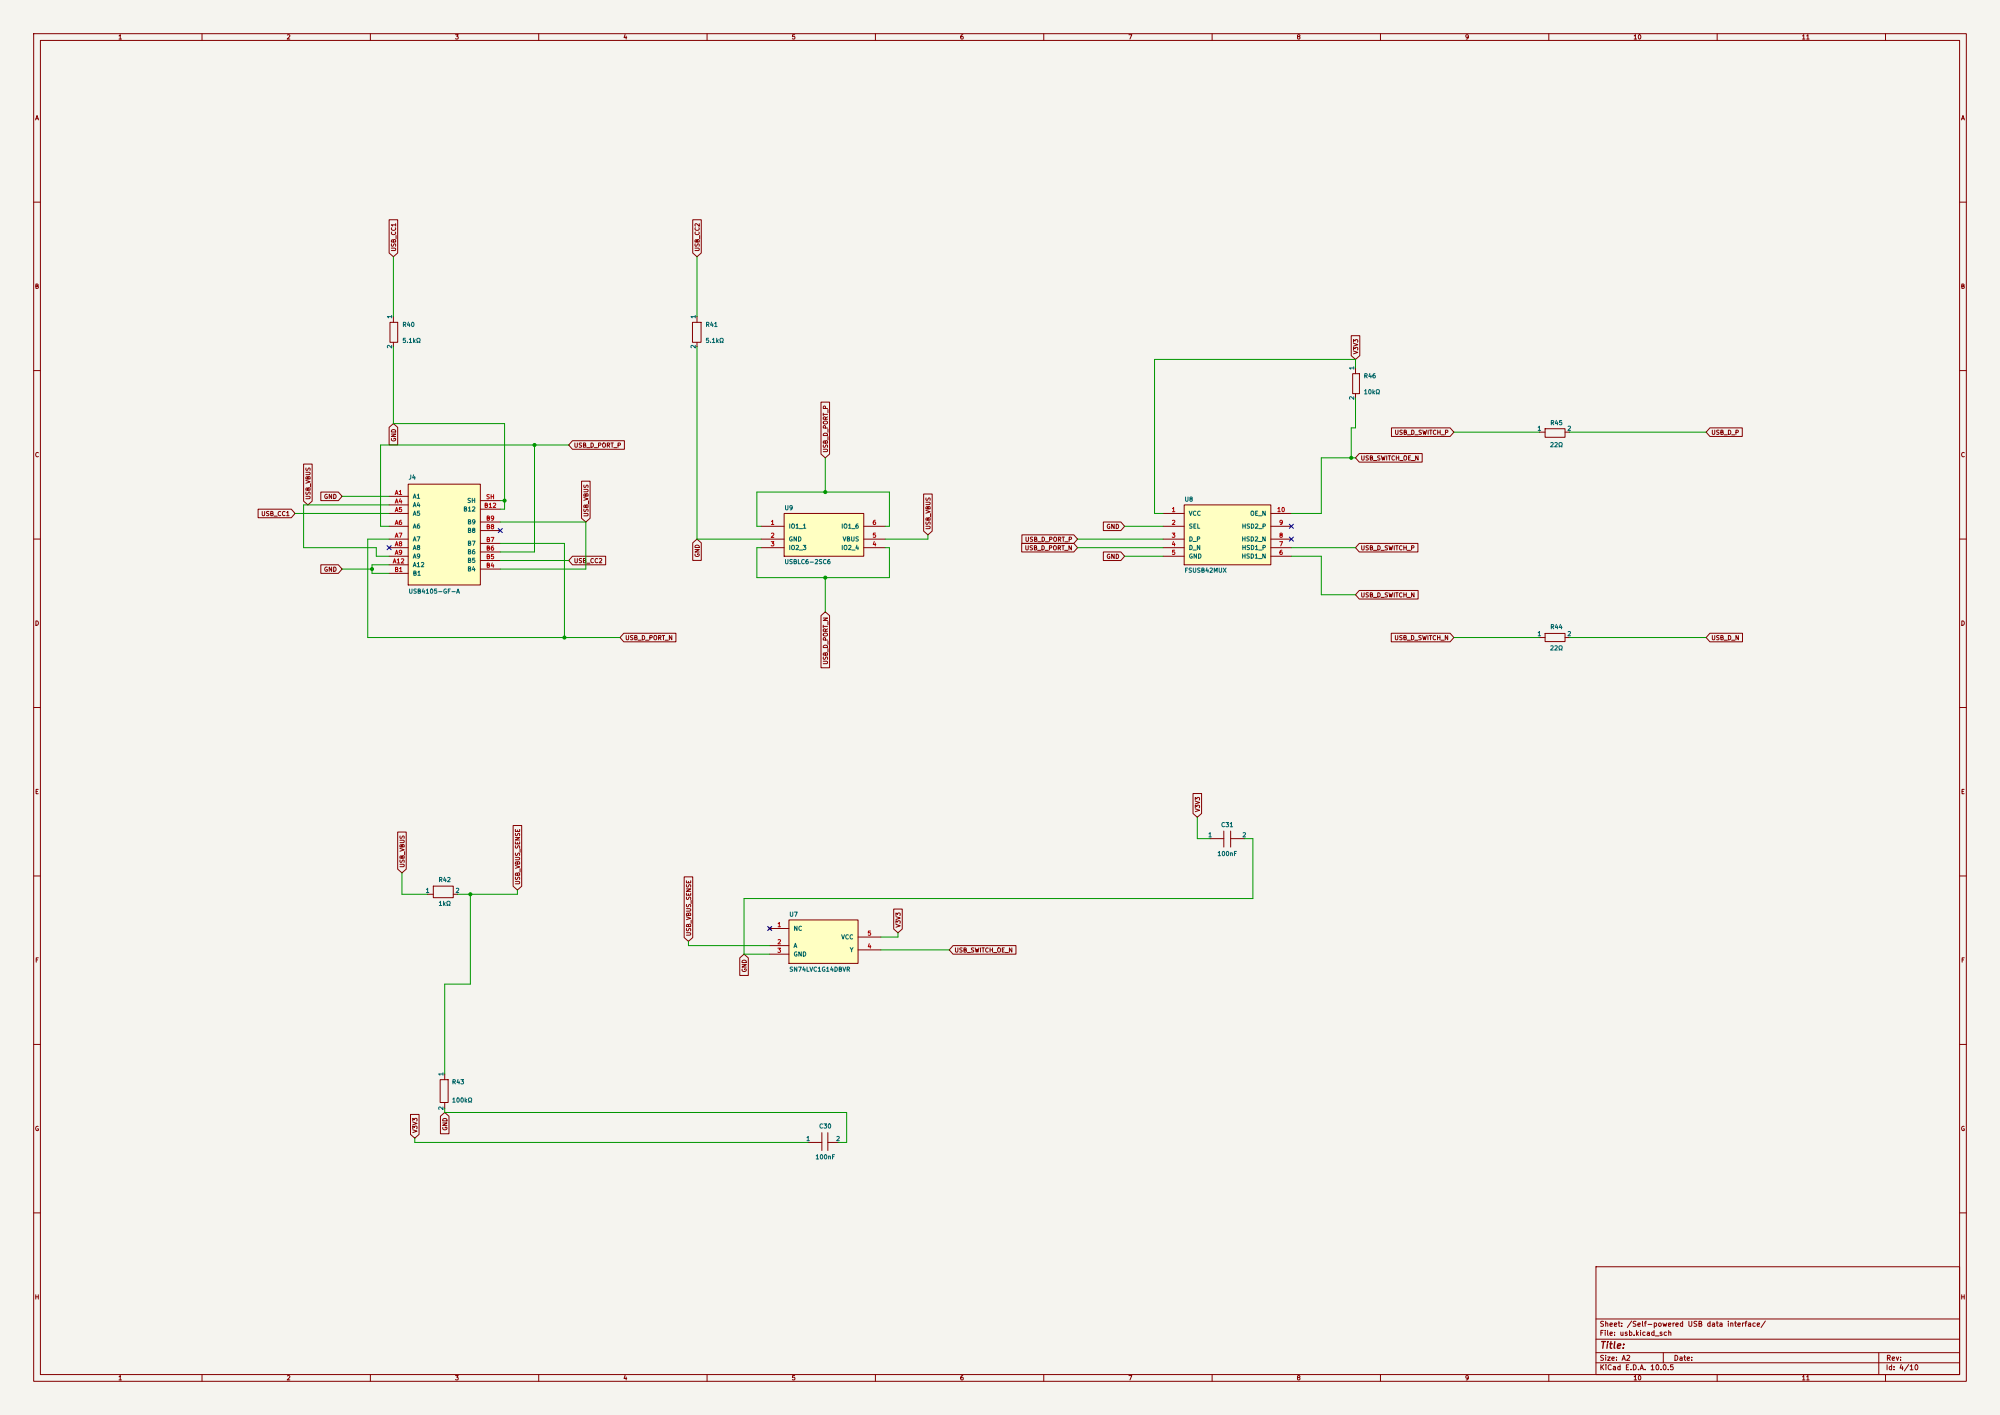
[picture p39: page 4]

Sheet: /Self-powered USB data interface/
File: usb.kicad_sch

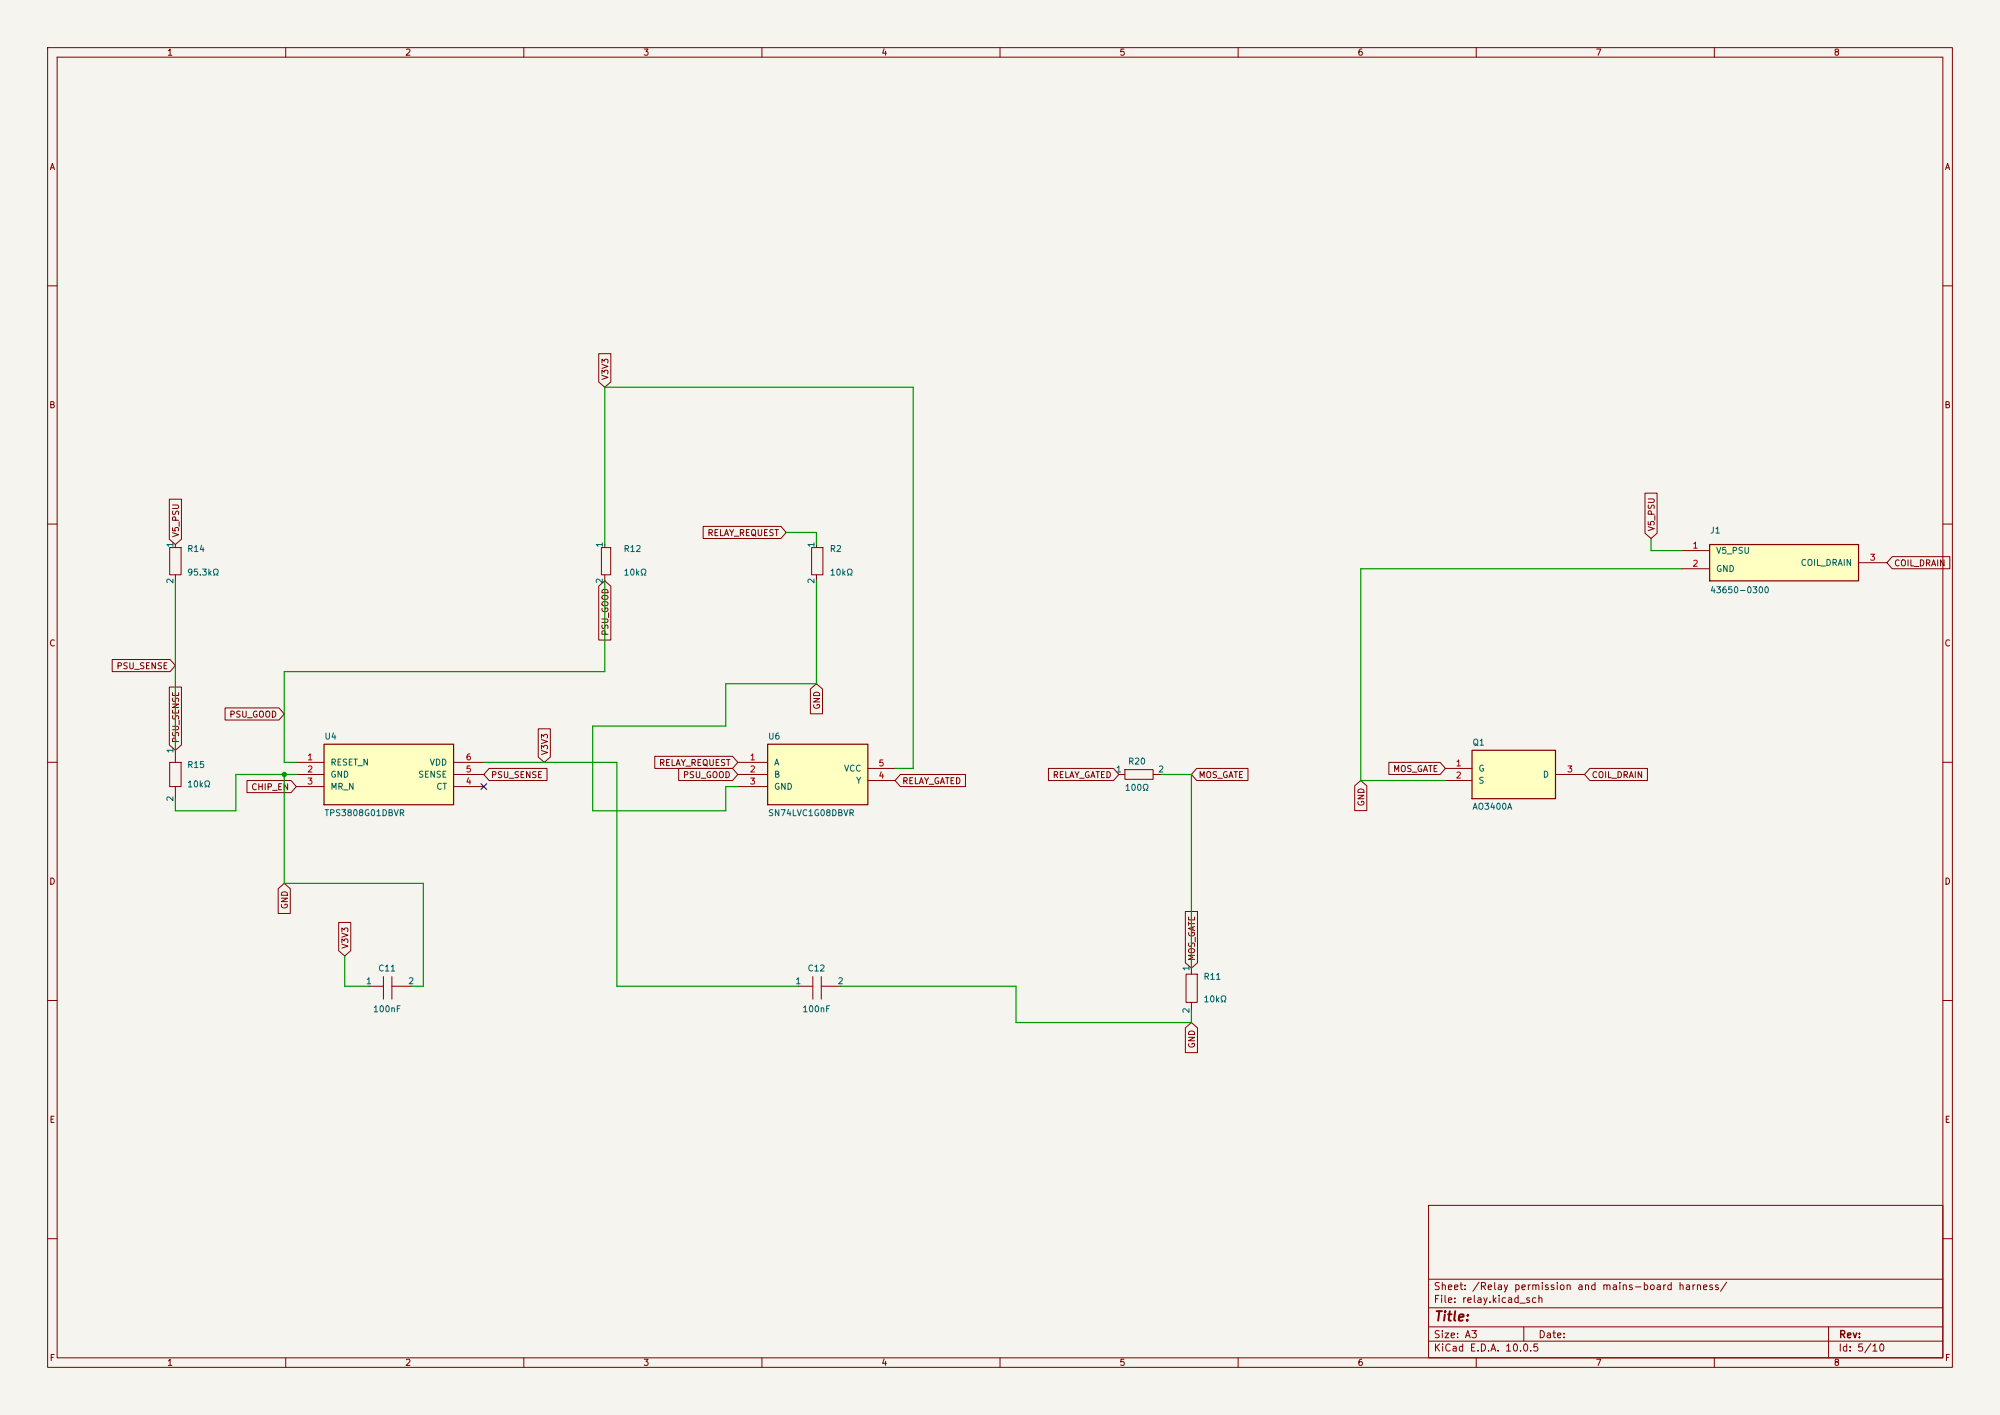
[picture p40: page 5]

Sheet: /Relay permission and mains-board harness/
File: relay.kicad_sch

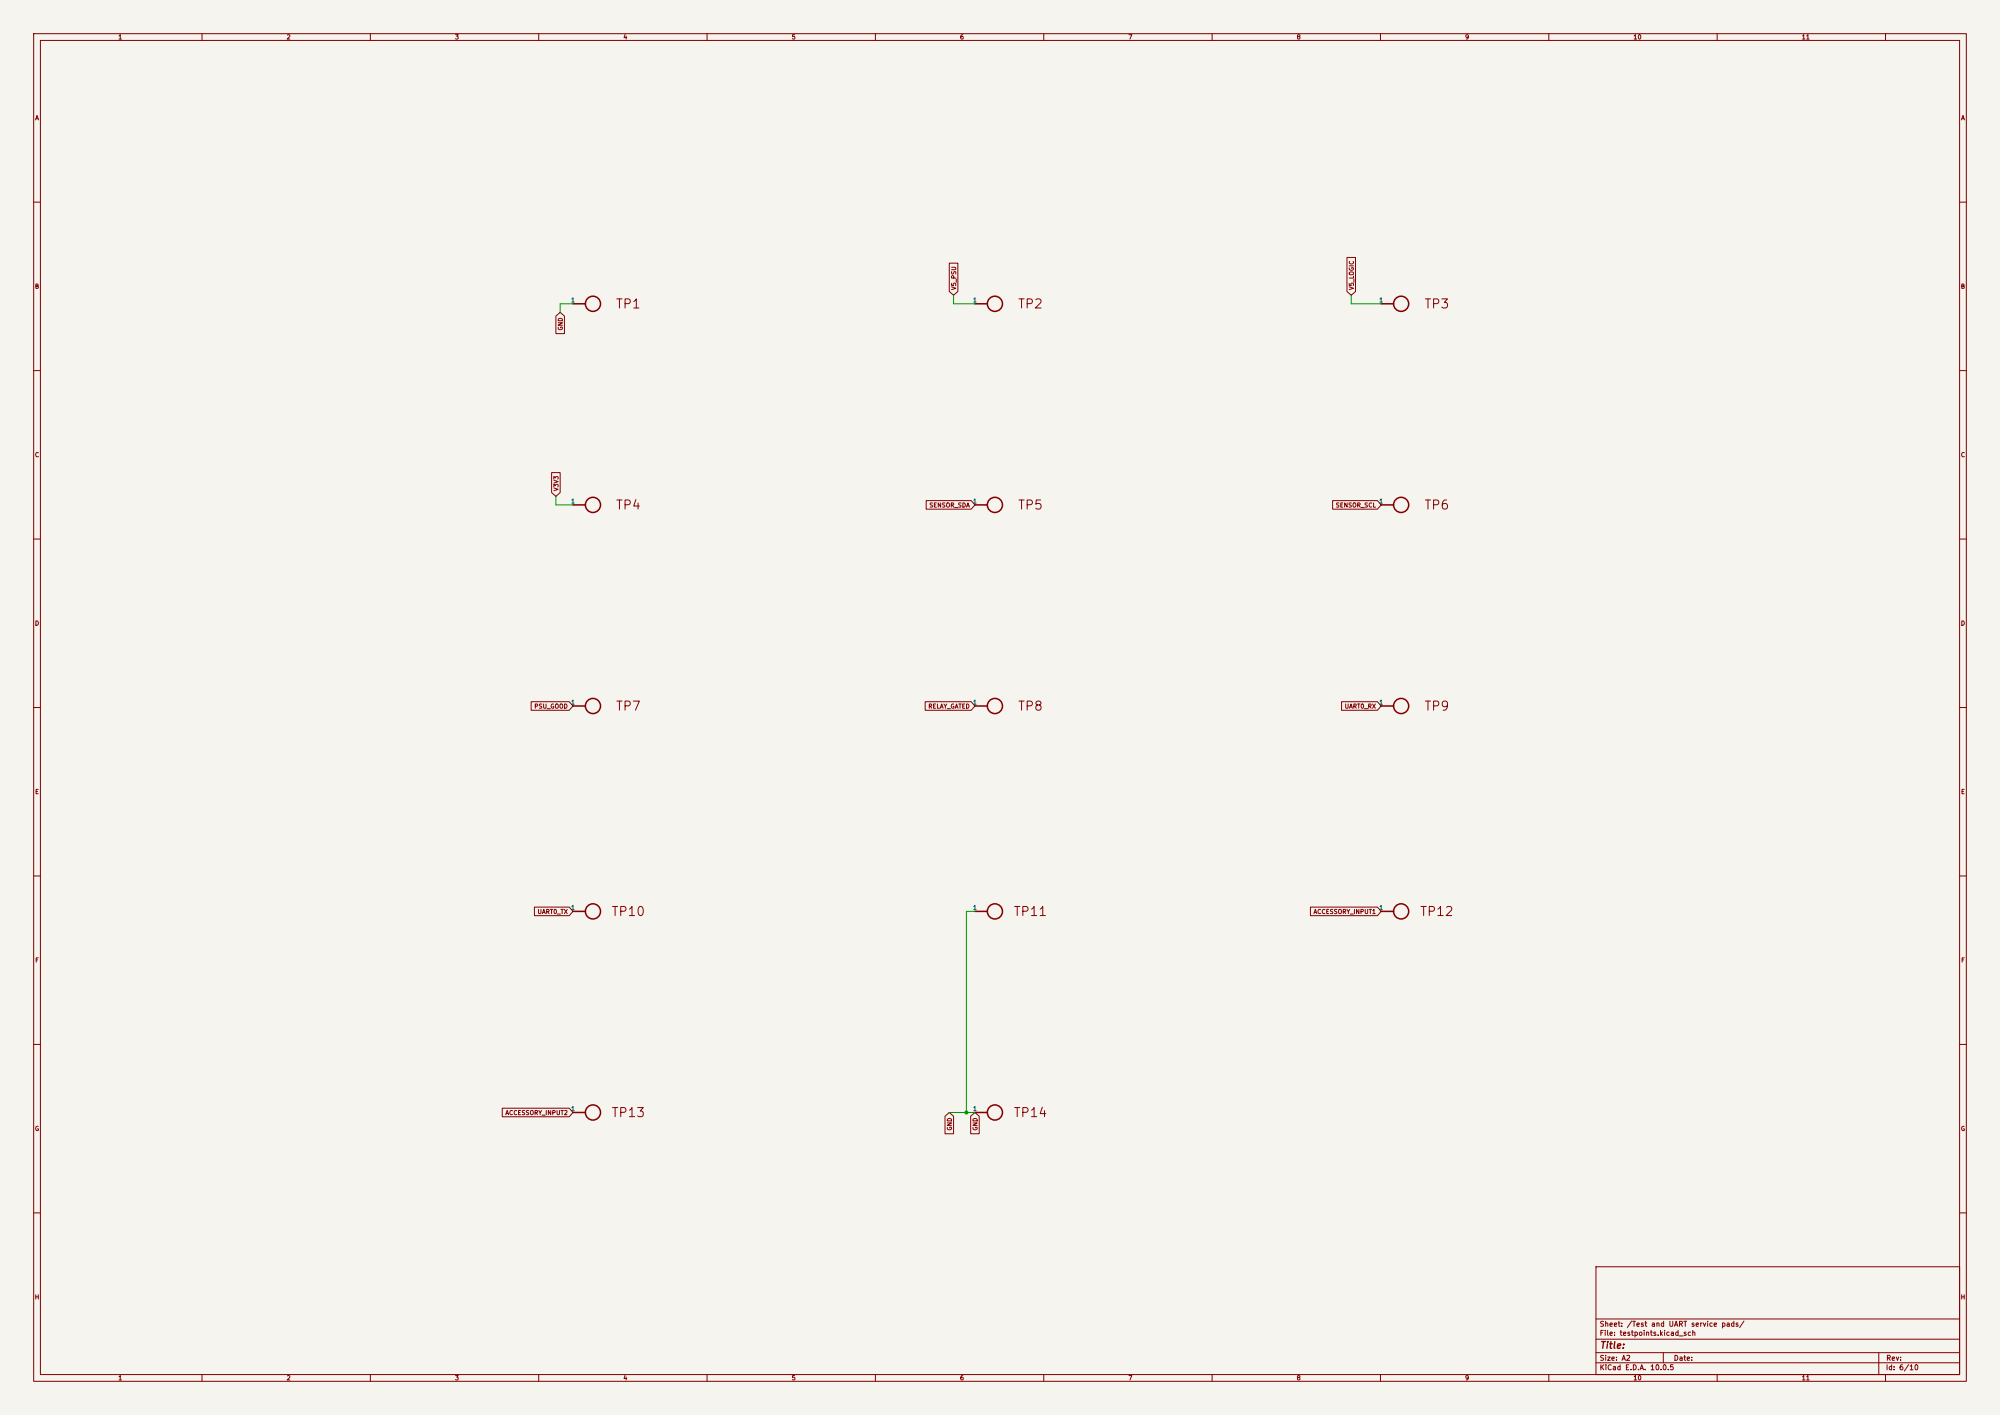
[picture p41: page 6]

Sheet: /Test and UART service pads/
File: testpoints.kicad_sch

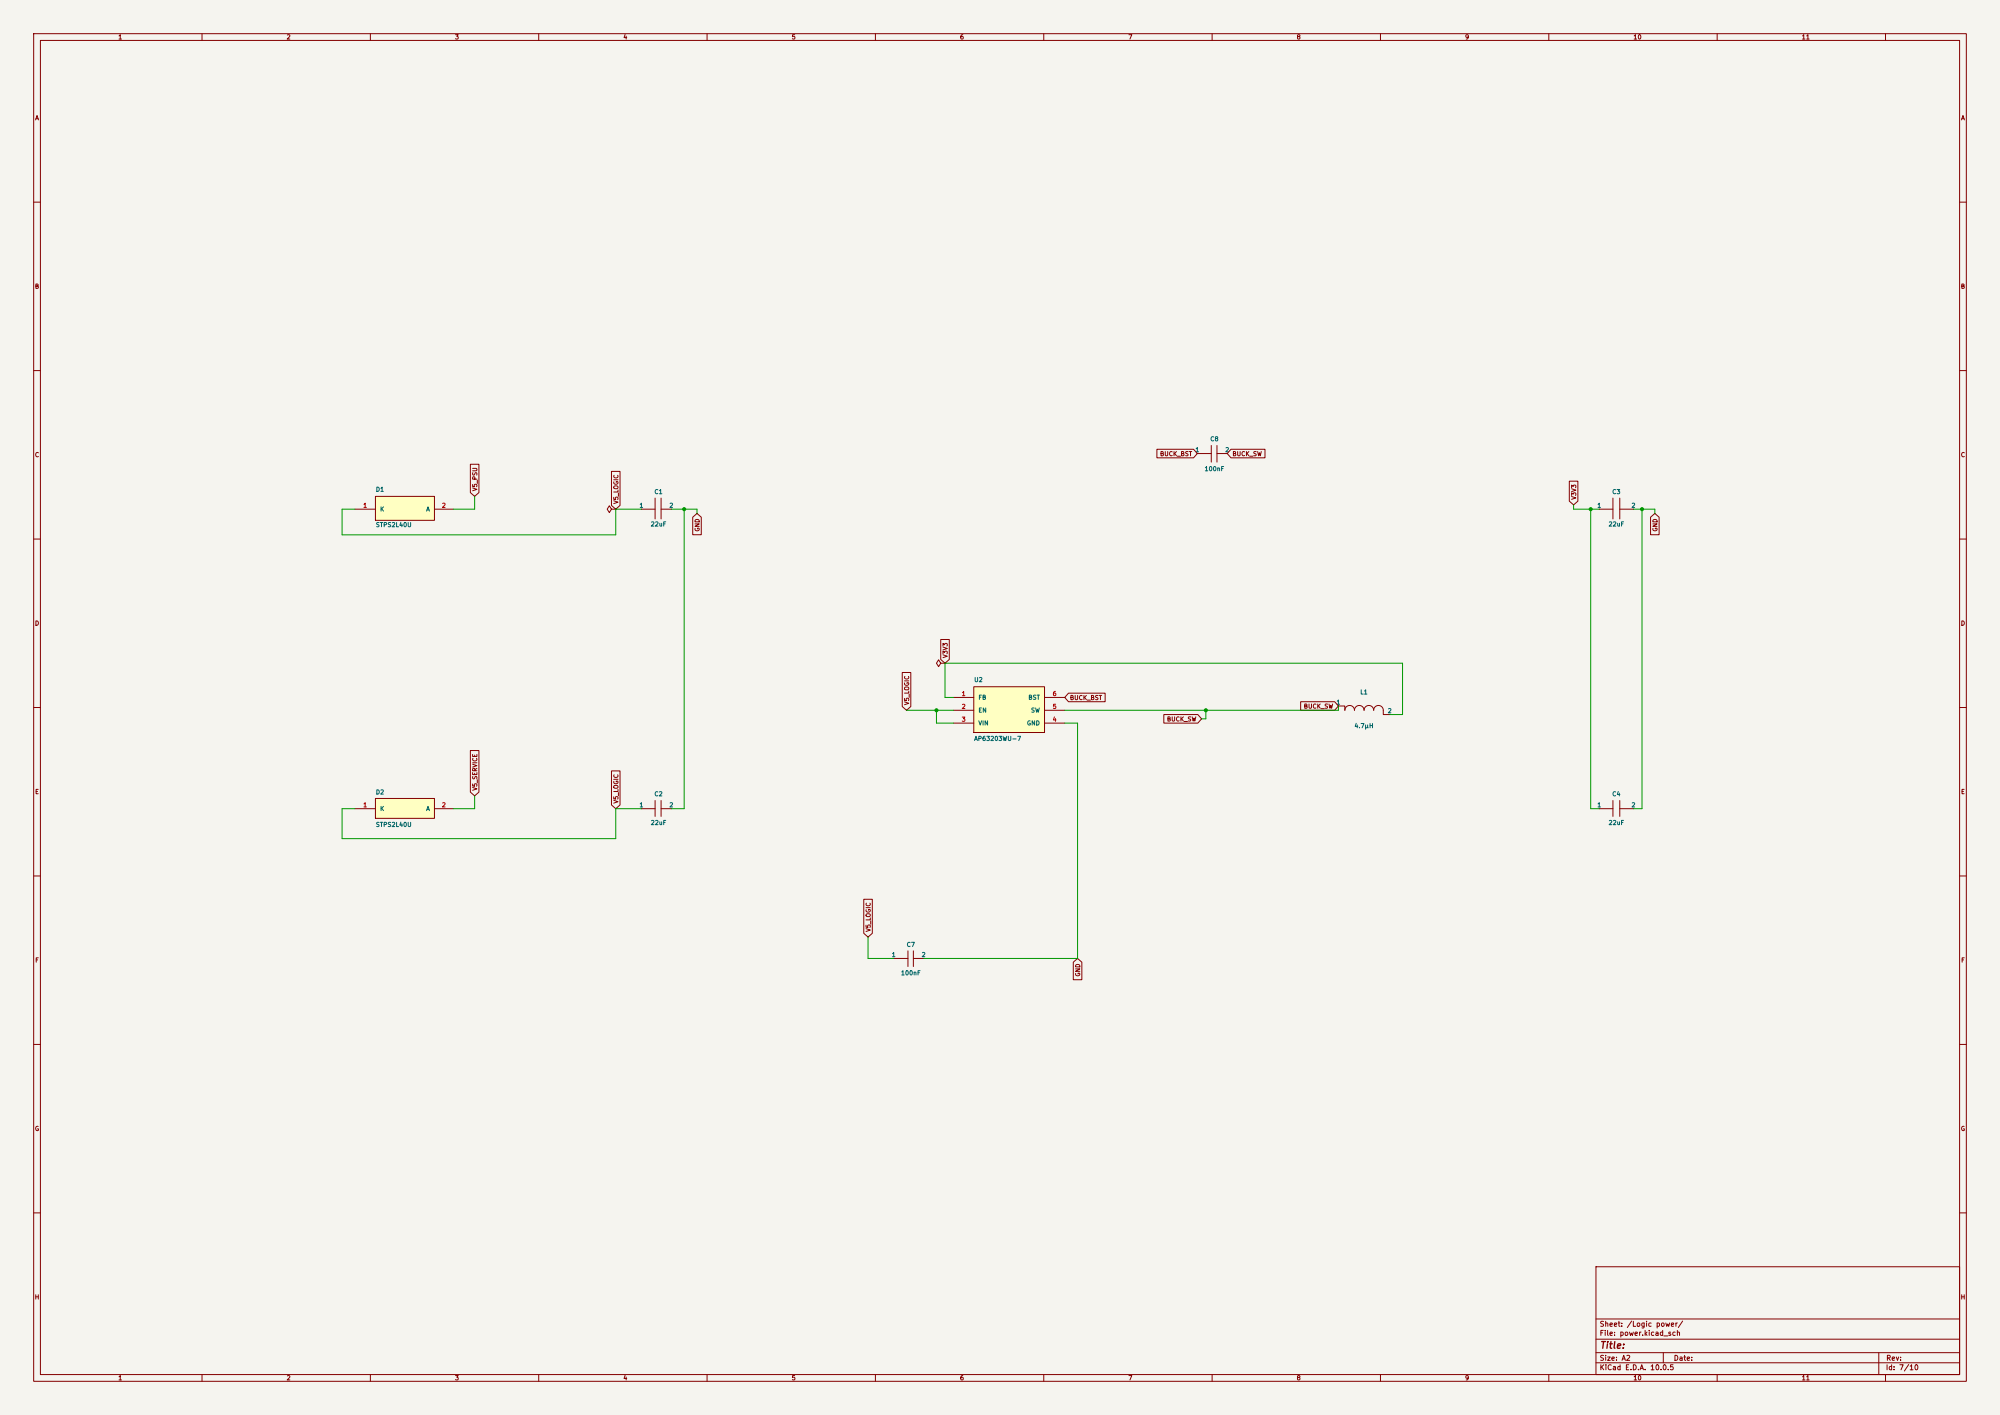
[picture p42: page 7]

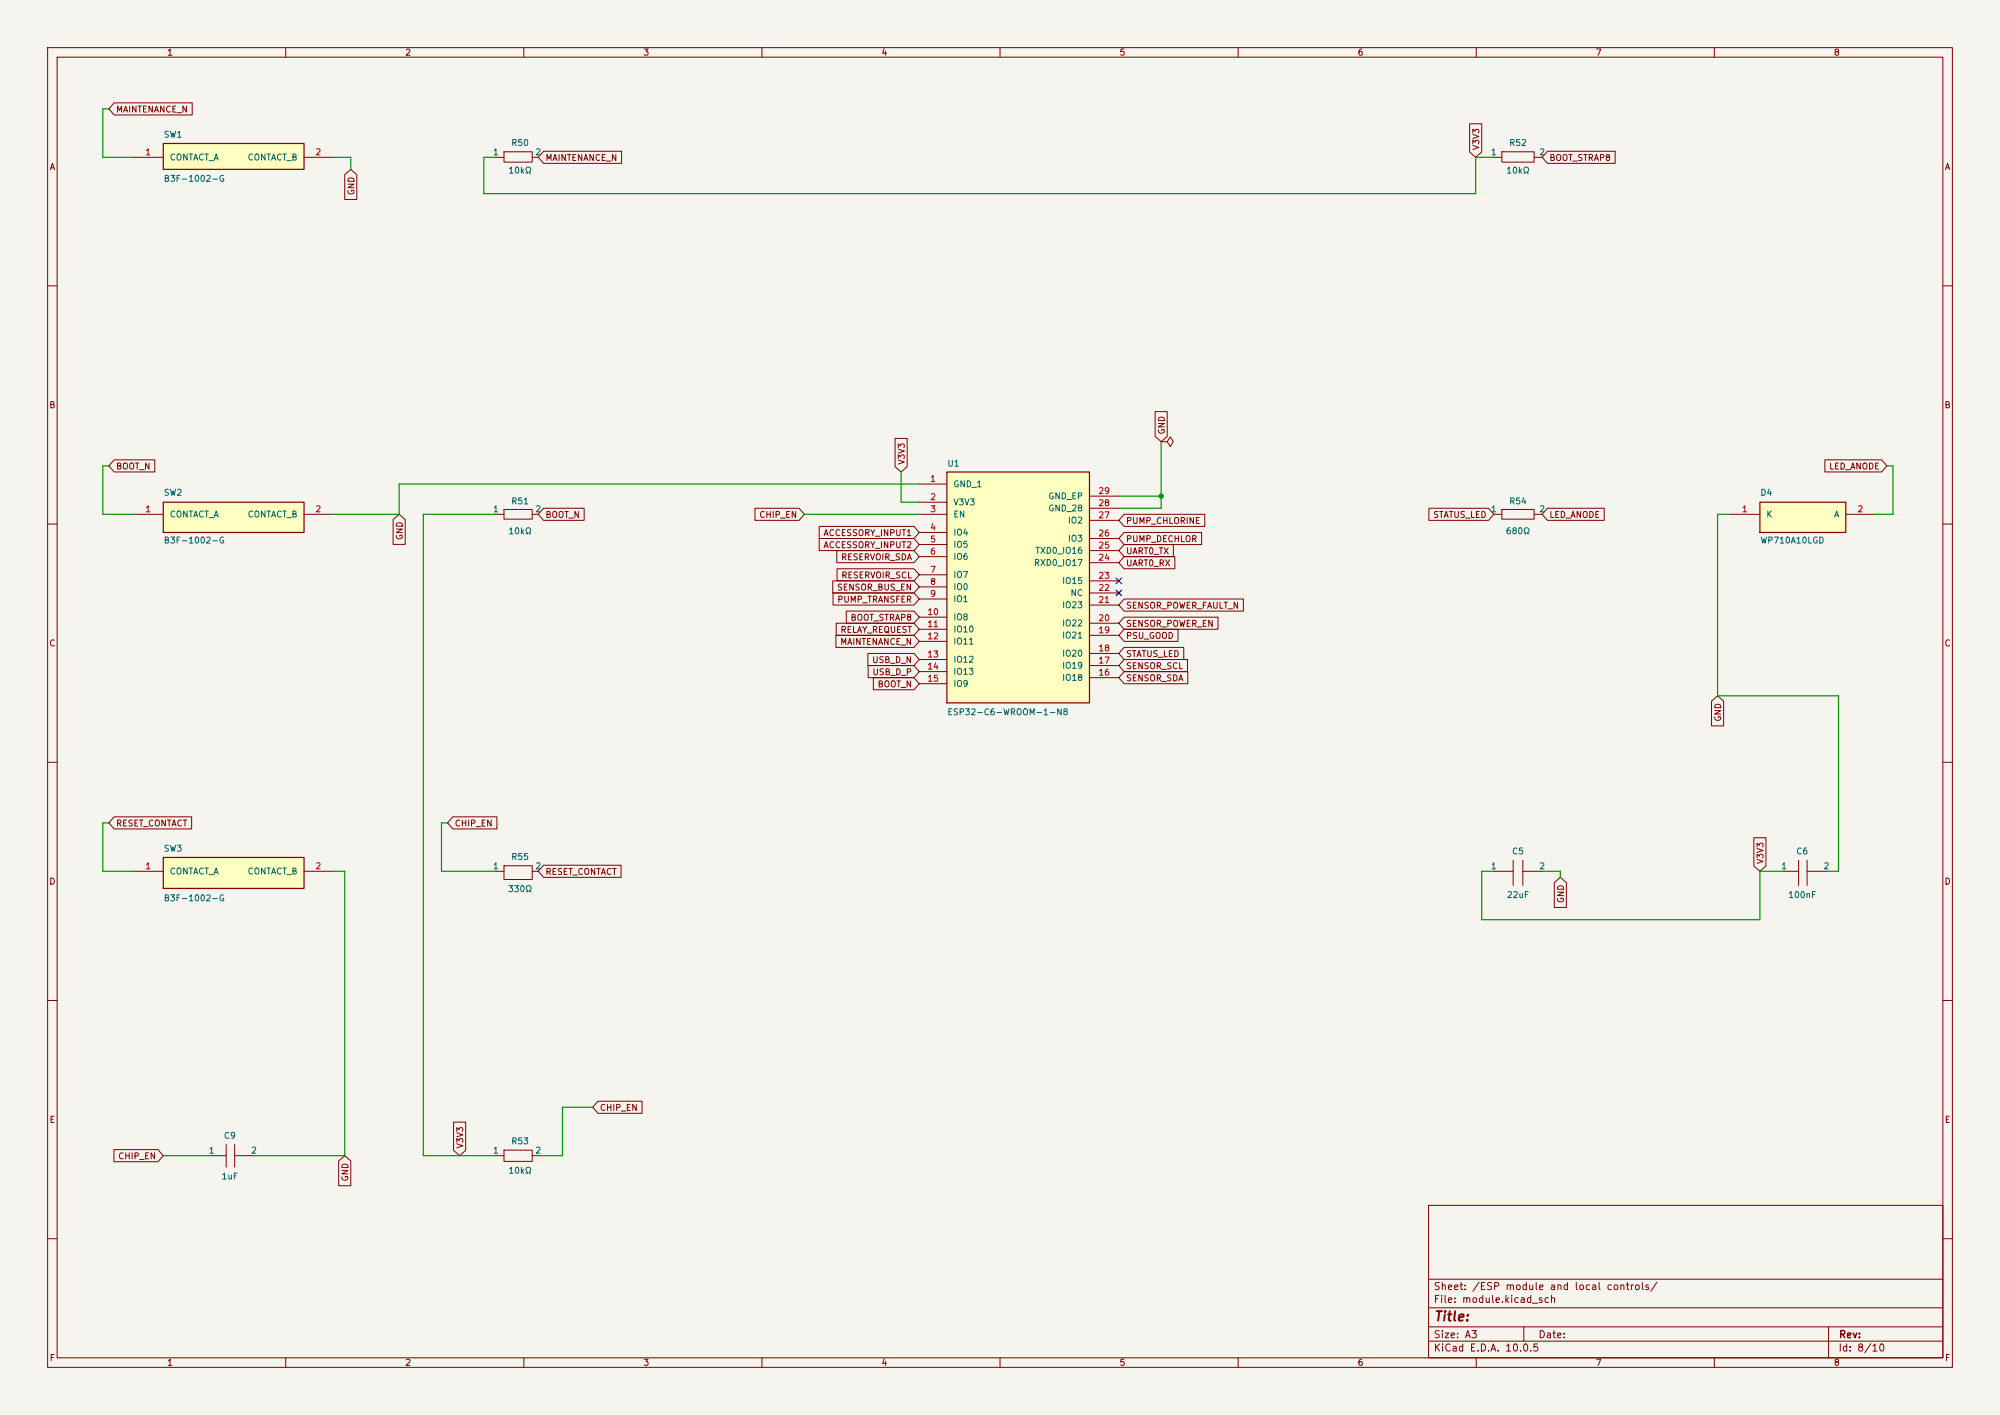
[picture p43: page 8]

Sheet: /ESP module and local controls/
File: module.kicad_sch


Sheet: /Future pump outputs/
File: pumps.kicad_sch


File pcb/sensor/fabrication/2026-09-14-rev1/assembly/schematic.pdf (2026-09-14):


Tank sensor, local 3.3 V and stored dry baseline

Size: A4 | Rev:
KiCad E.D.A. 10.0.5 | Id: 1/2


Sheet: /Tank sensor, local 3.3 V and stored dry baseline/
File: tanksensor.kicad_sch
Title:

Size: A1 | Rev:
KiCad E.D.A. 10.0.5 | Id: 2/2

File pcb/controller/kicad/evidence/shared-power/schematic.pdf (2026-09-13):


Relay permission and mains-board harness

Known-adapter service input

File: expansion-source/relay.kicad_sch

File: expansion-source/power.kicad_sch

File: expansion-source/service.kicad_sch

ESP module and local controls

Self-powered USB data interface

Protected sensor feed and buffered bus

File: expansion-source/module.kicad_sch

File: expansion-source/usb.kicad_sch

File: expansion-source/sensorinterface.kicad_sch

Future pump outputs File: expansion-source/pumps.kicad_sch

Test and UART service pads

Reservoir sensor File: expansion-source/reservoir.kicad_sch

File: expansion-source/testpoints.kicad_sch

Size: A4 | Rev:
KiCad E.D.A. 10.0.5 | Id: 1/10


Sheet: /Known-adapter service input/
File: service.kicad_sch
Title:


Sheet: /Protected sensor feed and buffered bus/
File: sensorinterface.kicad_sch
Title:


Sheet: /Self-powered USB data interface/
File: usb.kicad_sch


Sheet: /Relay permission and mains-board harness/
File: relay.kicad_sch


Sheet: /Test and UART service pads/
File: testpoints.kicad_sch



Sheet: /ESP module and local controls/
File: module.kicad_sch


Sheet: /Future pump outputs/
File: pumps.kicad_sch


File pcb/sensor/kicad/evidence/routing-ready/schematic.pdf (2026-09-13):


Tank sensor, local 3.3 V and stored dry baseline

Size: A4 | Rev:
KiCad E.D.A. 10.0.5 | Id: 1/2


Sheet: /Tank sensor, local 3.3 V and stored dry baseline/
File: tanksensor.kicad_sch
Title:

Size: A1 | Rev:
KiCad E.D.A. 10.0.5 | Id: 2/2

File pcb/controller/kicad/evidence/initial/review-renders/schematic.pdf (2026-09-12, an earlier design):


Relay permission and mains-board harness

Protected isolated service input

ESP module and local controls

Self-powered USB data interface

Protected sensor feed and buffered bus

Test and UART service pads

Size: A4 | Rev:
KiCad E.D.A. 10.0.5 | Id: 1/8


Sheet: /Relay permission and mains-board harness/
File: relay.kicad_sch
Title:



Sheet: /Protected isolated service input/
File: service.kicad_sch


Sheet: /ESP module and local controls/
File: module.kicad_sch


Sheet: /Self-powered USB data interface/
File: usb.kicad_sch


Sheet: /Protected sensor feed and buffered bus/
File: sensorinterface.kicad_sch


Sheet: /Test and UART service pads/
File: testpoints.kicad_sch

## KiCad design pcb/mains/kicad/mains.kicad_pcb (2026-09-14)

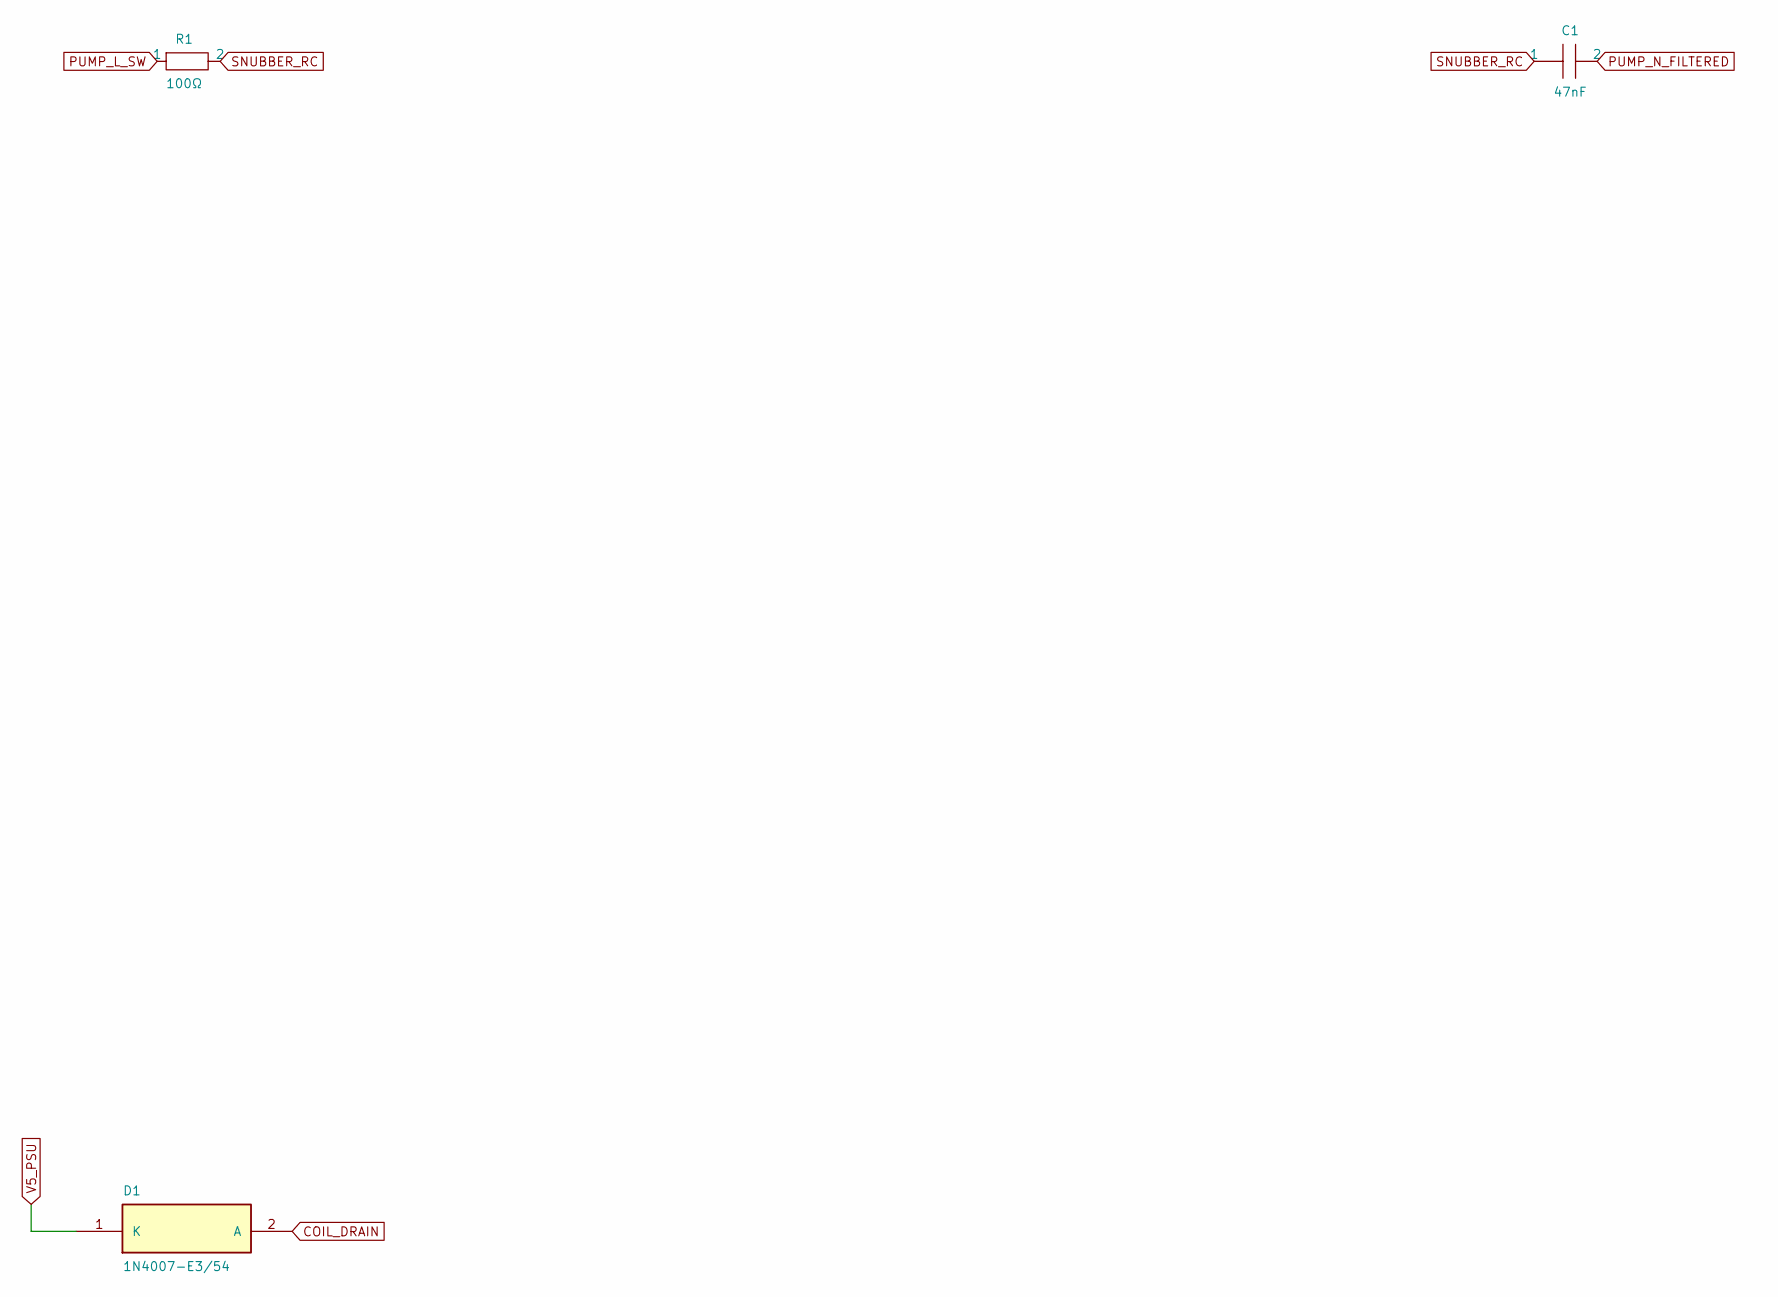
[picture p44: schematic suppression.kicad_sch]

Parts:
C1: 47nF; Mains_C1; MPN B32921C3473K000
D1: 1N4007-E3/54; Mains_D1; MPN 1N4007-E3/54
R1: 100Ω; Mains_R1; MPN PR02FS0201000KA100

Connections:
COIL_DRAIN: D1.2 (A); also elsewhere on the board
PUMP_L_SW: R1.1; also elsewhere on the board
PUMP_N_FILTERED: C1.2; also elsewhere on the board
SNUBBER_RC: C1.1, R1.2
V5_PSU: D1.1 (K); also elsewhere on the board

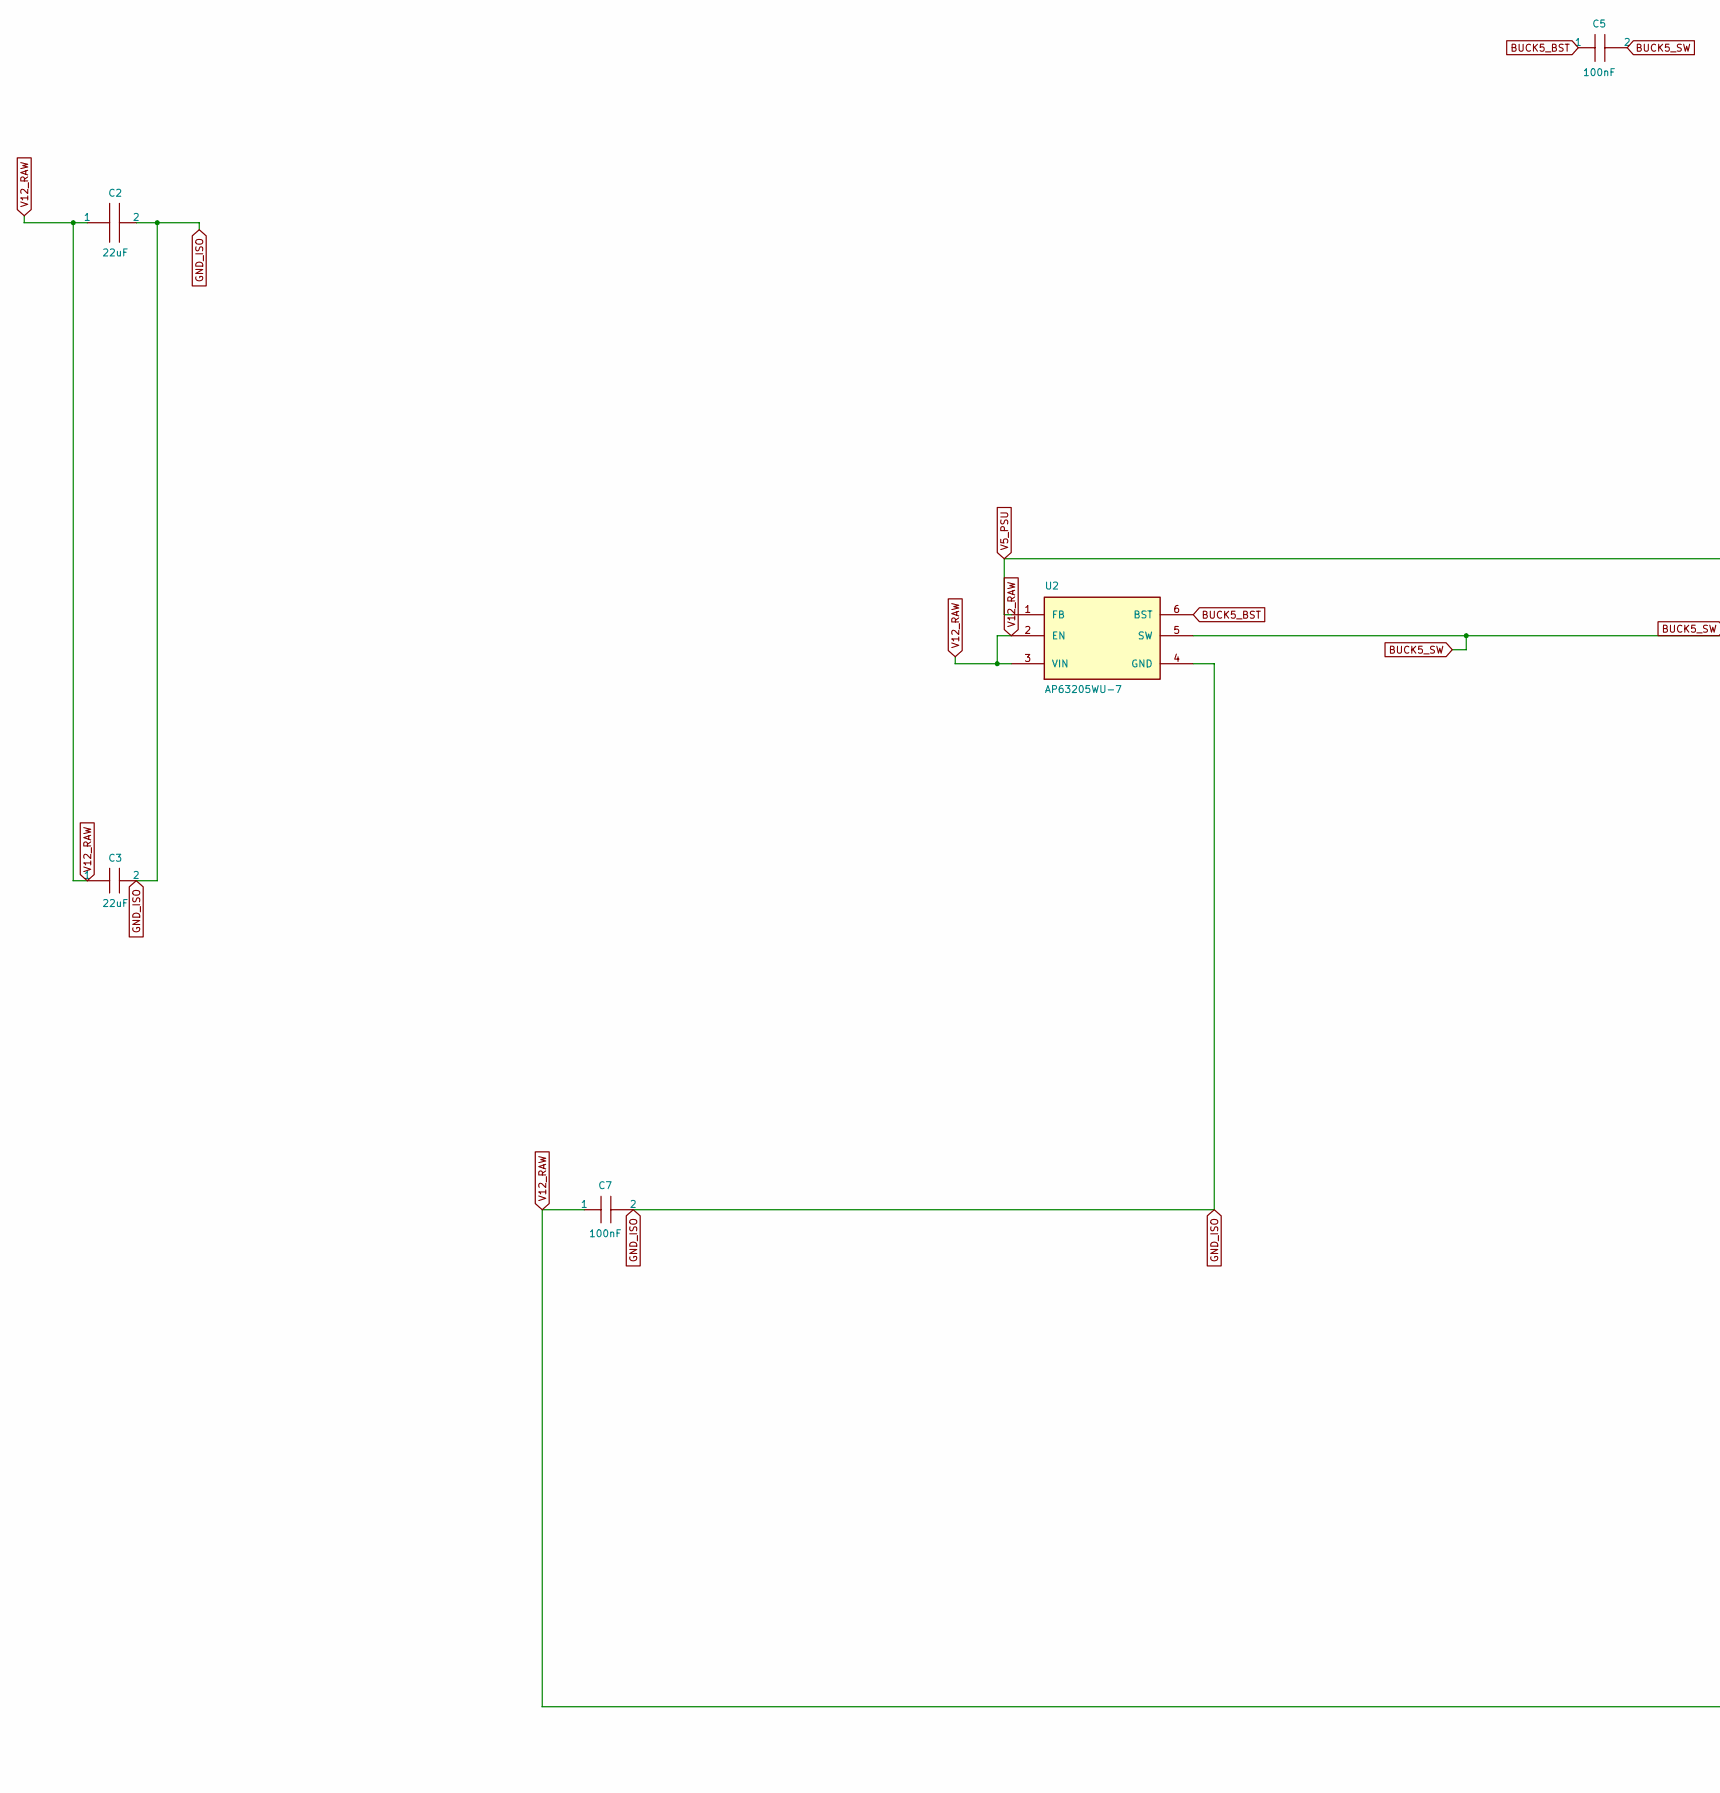
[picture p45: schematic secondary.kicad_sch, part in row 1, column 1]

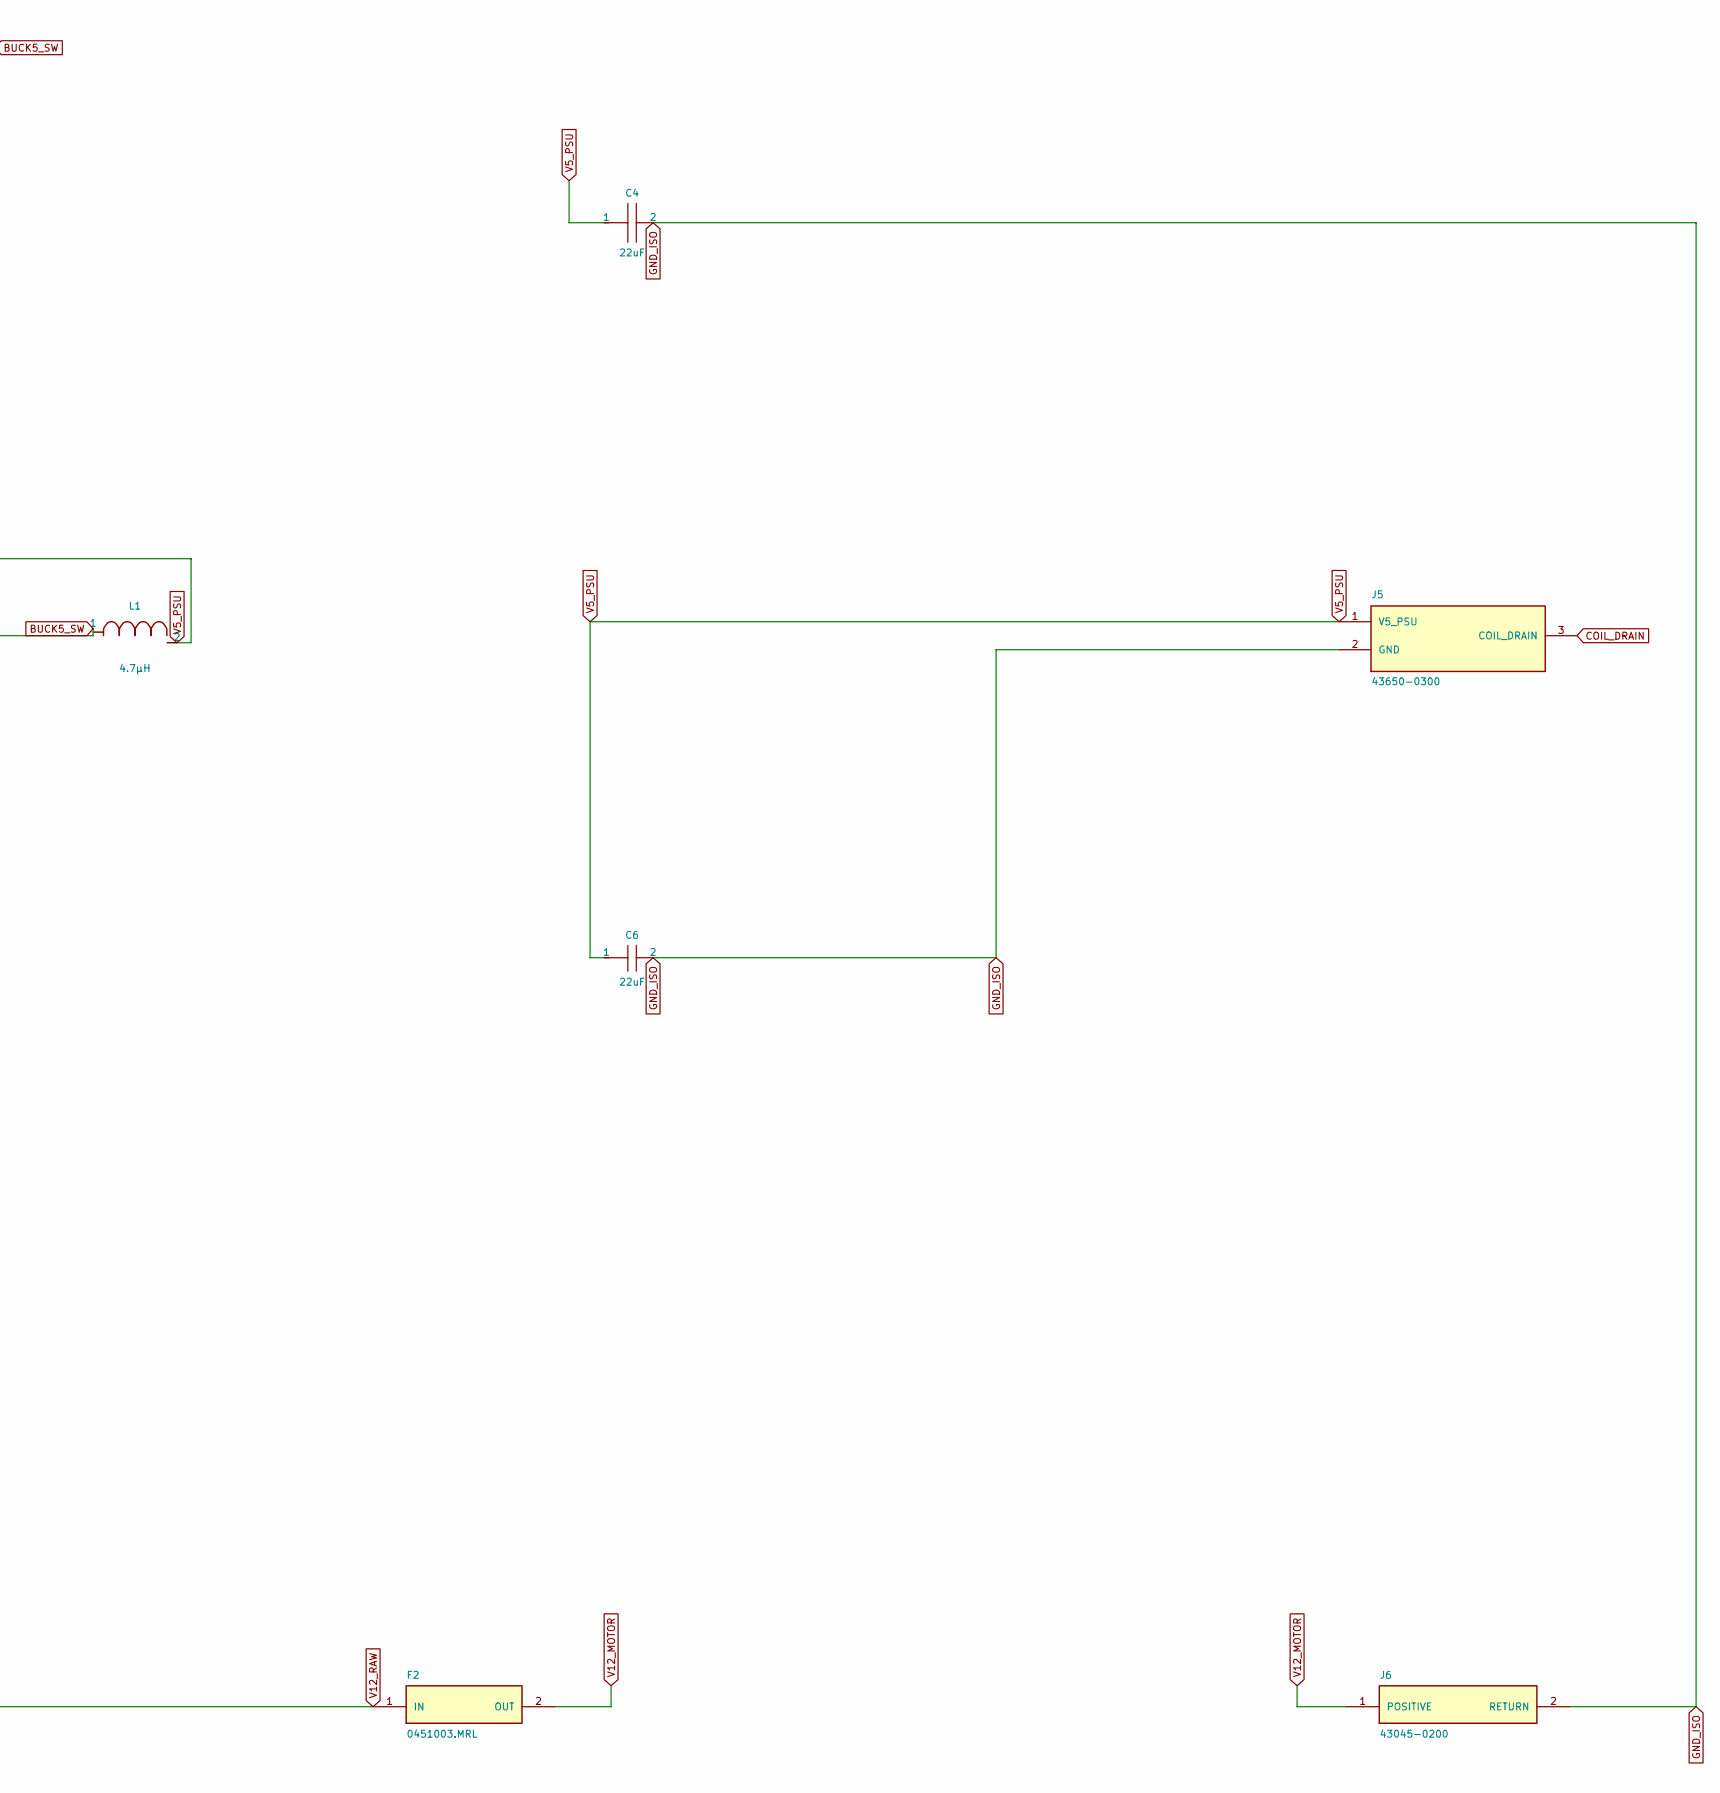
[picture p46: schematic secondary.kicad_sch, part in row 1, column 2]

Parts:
C2: 22uF; Mains_C2; MPN GRM32ER71E226ME15L
C3: 22uF; Mains_C3; MPN GRM32ER71E226ME15L
C4: 22uF; Mains_C4; MPN GRM32ER71E226ME15L
C5: 100nF; Mains_C5; MPN C1608X7R1H104K080AA
C6: 22uF; Mains_C6; MPN GRM32ER71E226ME15L
C7: 100nF; Mains_C7; MPN C1608X7R1H104K080AA
F2: 0451003.MRL; Mains_F2; MPN 0451003.MRL
J5: 43650-0300; Mains_J5; MPN 43650-0300
J6: 43045-0200; Mains_J6; MPN 43045-0200
L1: 4.7µH; Mains_L1; MPN SRP5030TA-4R7M
U2: AP63205WU-7; Mains_U2; MPN AP63205WU-7

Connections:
BUCK5_BST: C5.1, U2.6 (BST)
BUCK5_SW: C5.2, L1.1, U2.5 (SW)
COIL_DRAIN: J5.3 (COIL_DRAIN); also elsewhere on the board
GND_ISO: C2.2, C3.2, C4.2, C6.2, C7.2, J5.2 (GND), J6.2 (RETURN), U2.4 (GND); also elsewhere on the board
V5_PSU: C4.1, C6.1, J5.1 (V5_PSU), L1.2, U2.1 (FB); also elsewhere on the board
V12_MOTOR: F2.2 (OUT), J6.1 (POSITIVE)
V12_RAW: C2.1, C3.1, C7.1, F2.1 (IN), U2.2 (EN), U2.3 (VIN); also elsewhere on the board

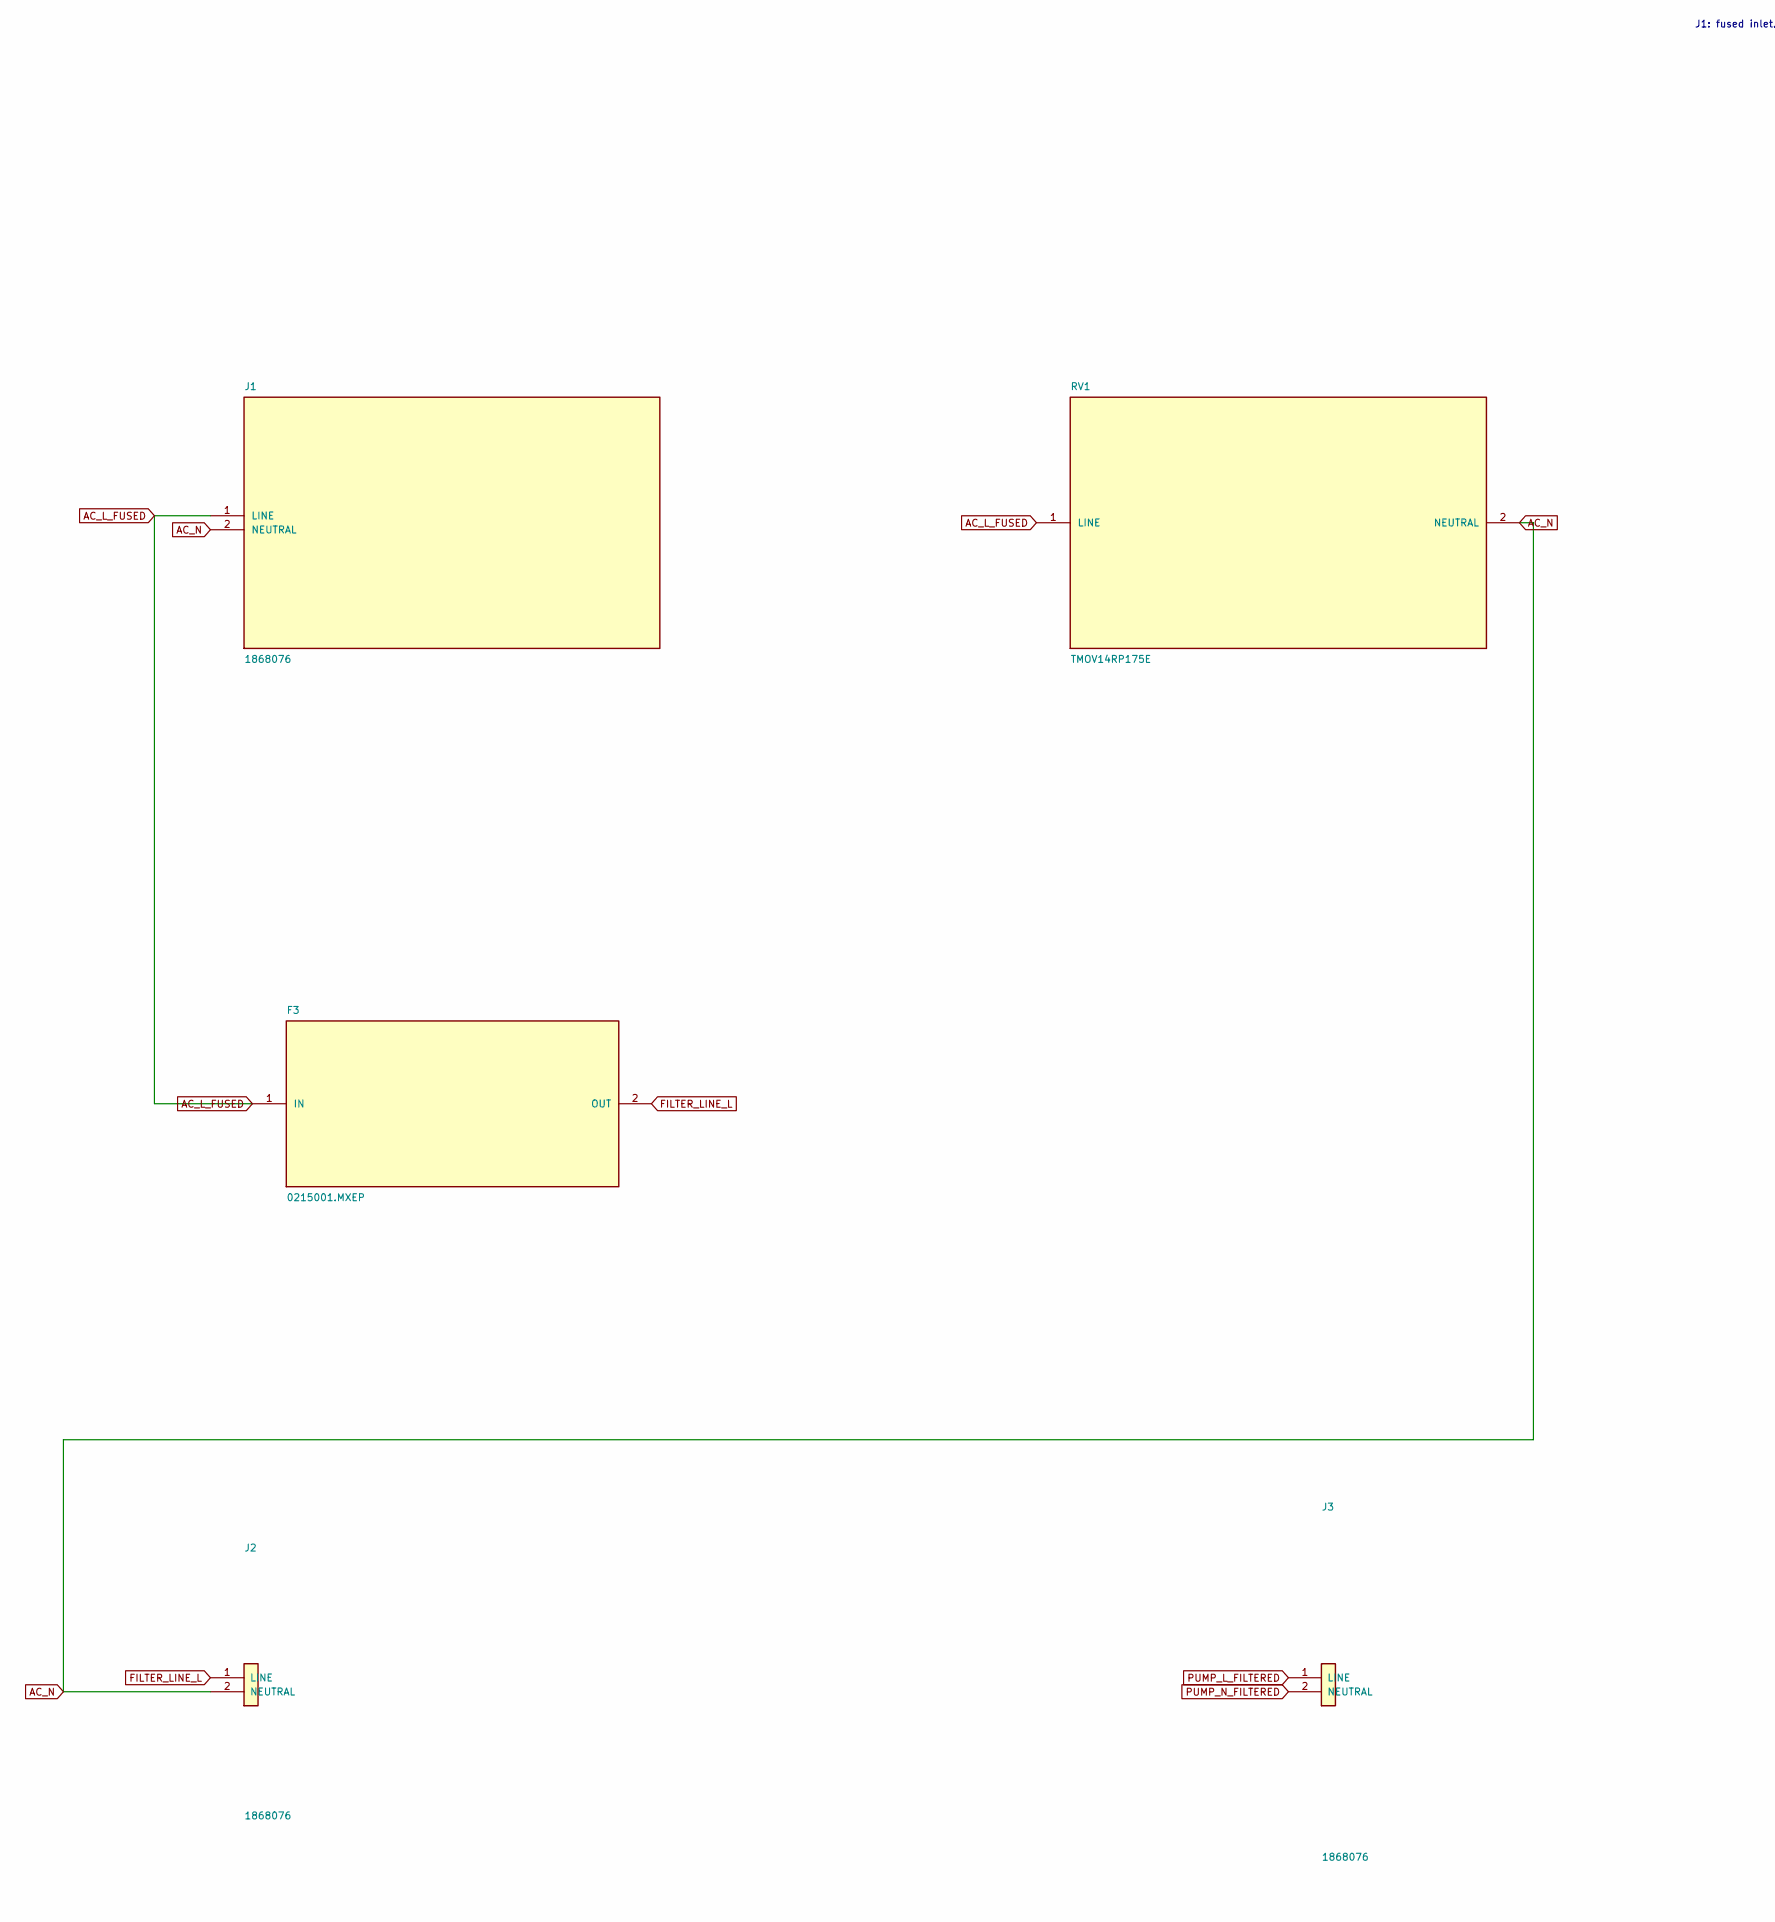
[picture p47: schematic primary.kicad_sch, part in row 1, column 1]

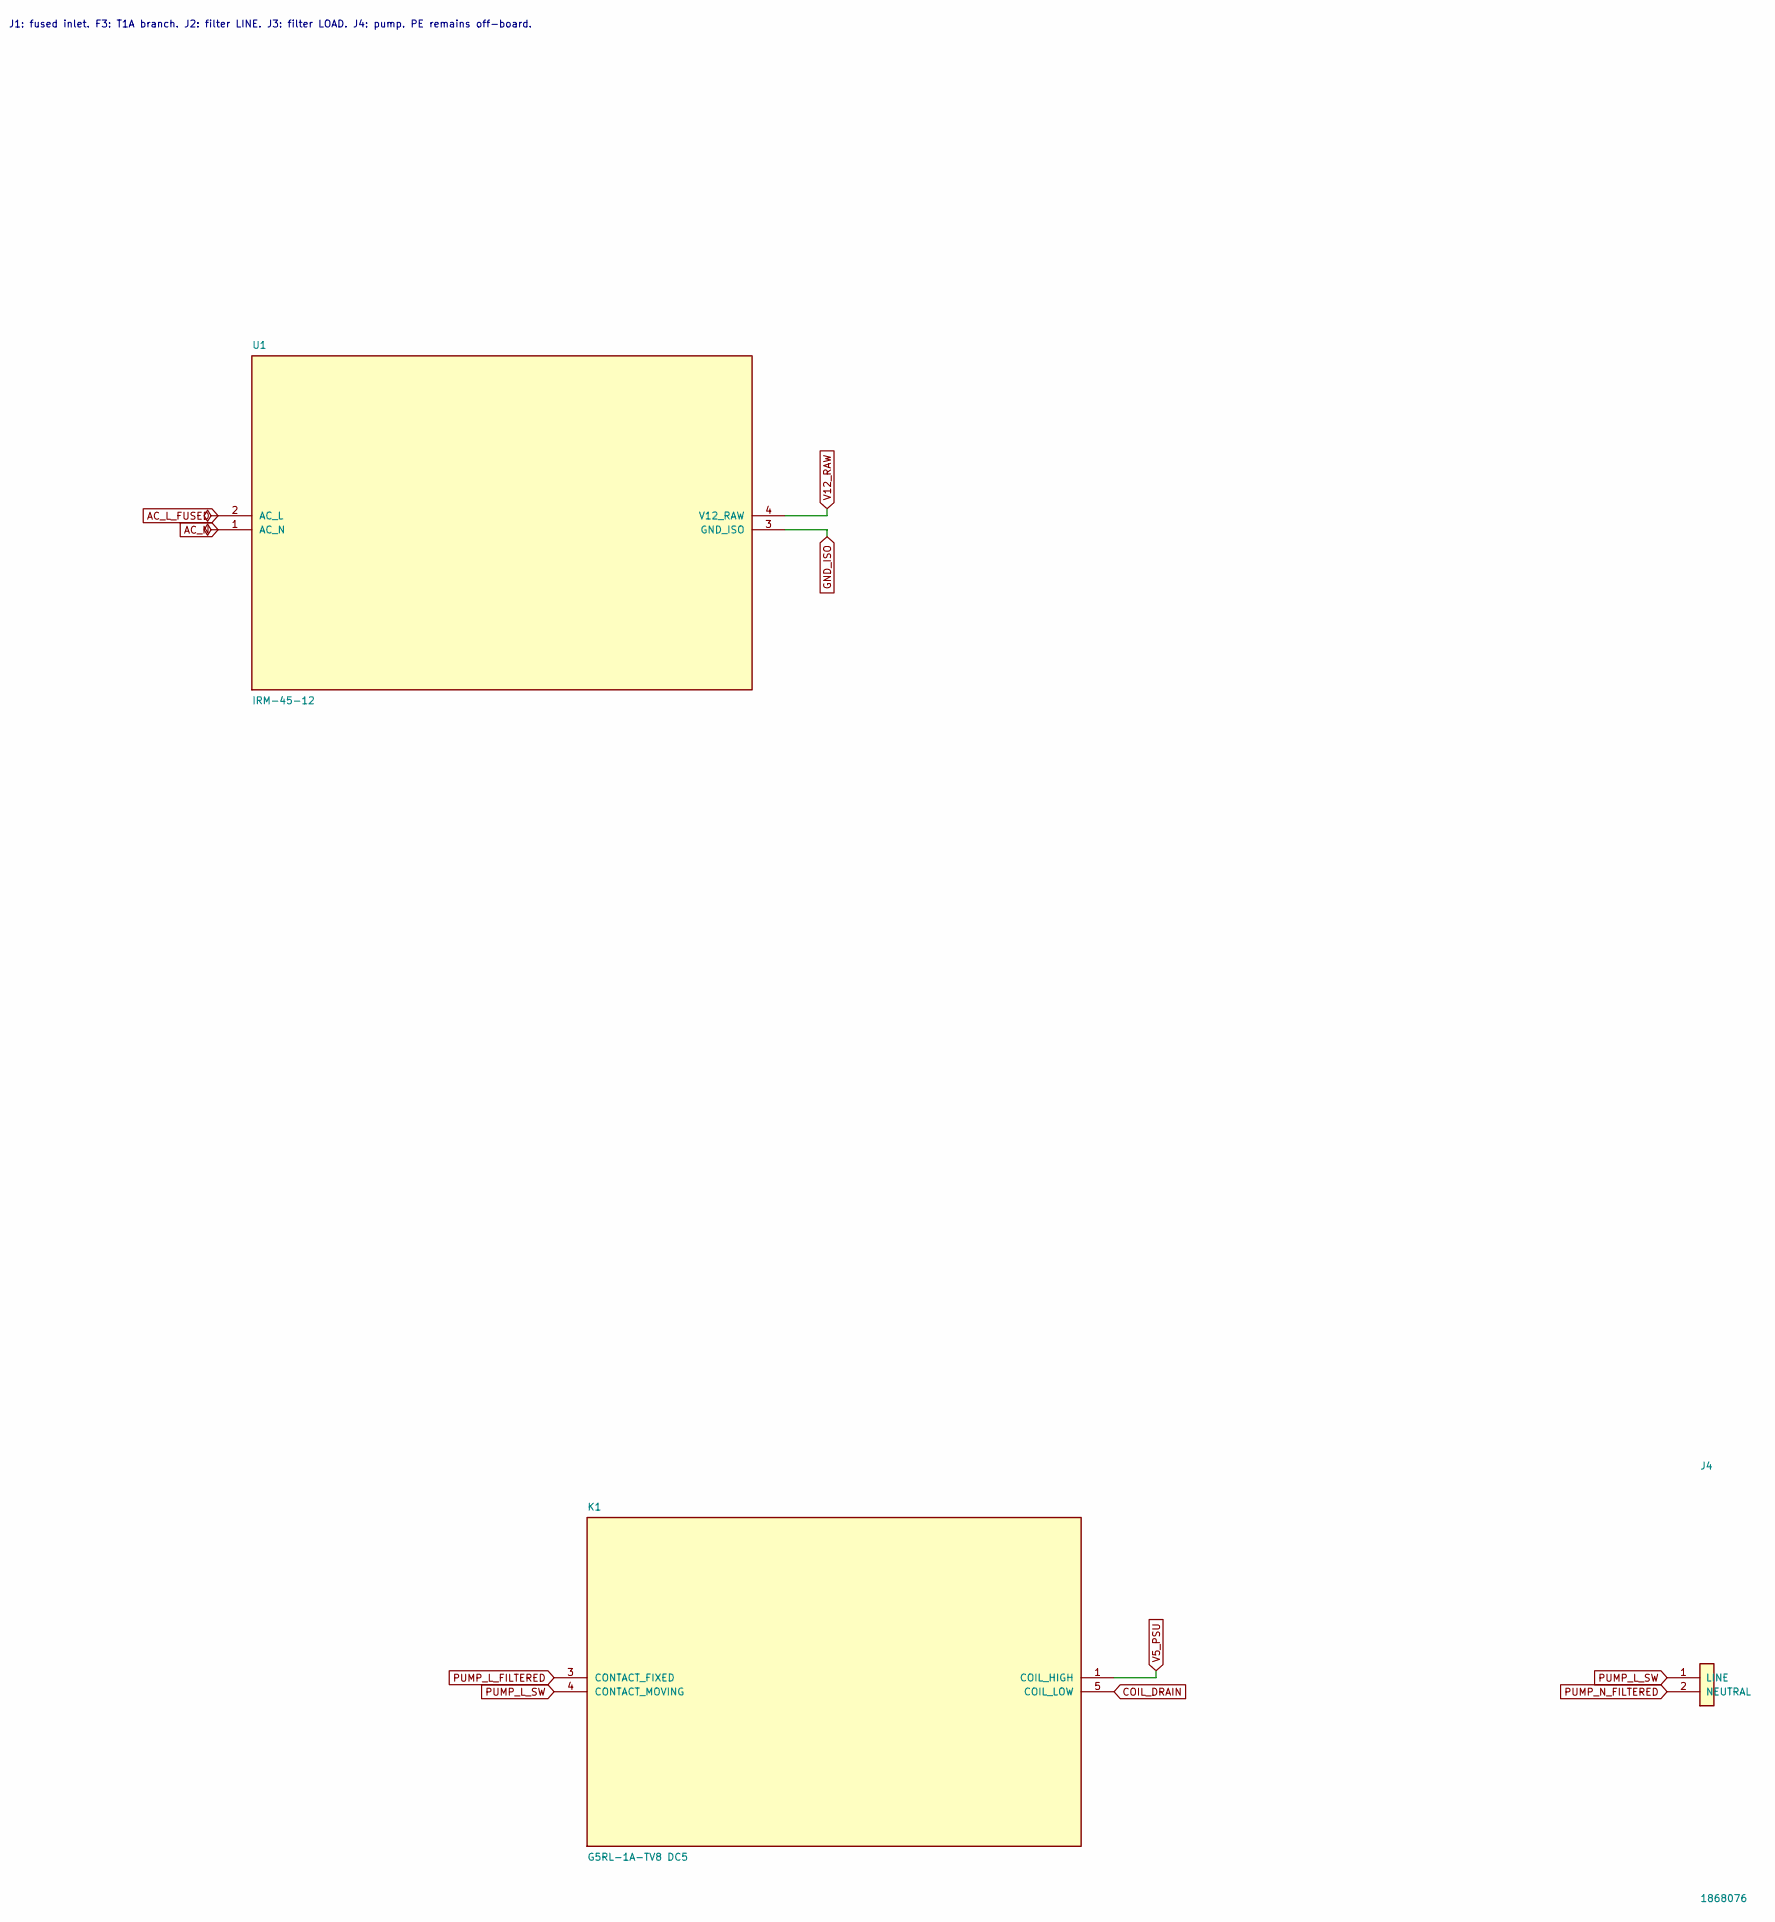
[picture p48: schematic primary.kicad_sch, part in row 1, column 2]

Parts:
F3: 0215001.MXEP; Mains_F3; MPN 0215001.MXEP
J1: 1868076; Mains_J1; MPN 1868076
J2: 1868076; Mains_J2; MPN 1868076
J3: 1868076; Mains_J3; MPN 1868076
J4: 1868076; Mains_J4; MPN 1868076
K1: G5RL-1A-TV8 DC5; Mains_K1; MPN G5RL-1A-TV8 DC5
RV1: TMOV14RP175E; Mains_RV1; MPN TMOV14RP175E
U1: IRM-45-12; Mains_U1; MPN IRM-45-12

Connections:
AC_L_FUSED: F3.1 (IN), J1.1 (LINE), RV1.1 (LINE), U1.2 (AC_L)
AC_N: J1.2 (NEUTRAL), J2.2 (NEUTRAL), RV1.2 (NEUTRAL), U1.1 (AC_N)
COIL_DRAIN: K1.5 (COIL_LOW); also elsewhere on the board
FILTER_LINE_L: F3.2 (OUT), J2.1 (LINE)
GND_ISO: U1.3 (GND_ISO); also elsewhere on the board
PUMP_L_FILTERED: J3.1 (LINE), K1.3 (CONTACT_FIXED)
PUMP_L_SW: J4.1 (LINE), K1.4 (CONTACT_MOVING); also elsewhere on the board
PUMP_N_FILTERED: J3.2 (NEUTRAL), J4.2 (NEUTRAL); also elsewhere on the board
V5_PSU: K1.1 (COIL_HIGH); also elsewhere on the board
V12_RAW: U1.4 (V12_RAW); also elsewhere on the board

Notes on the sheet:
J1: fused inlet. F3: T1A branch. J2: filter LINE. J3: filter LOAD. J4: pump. PE remains off-board.

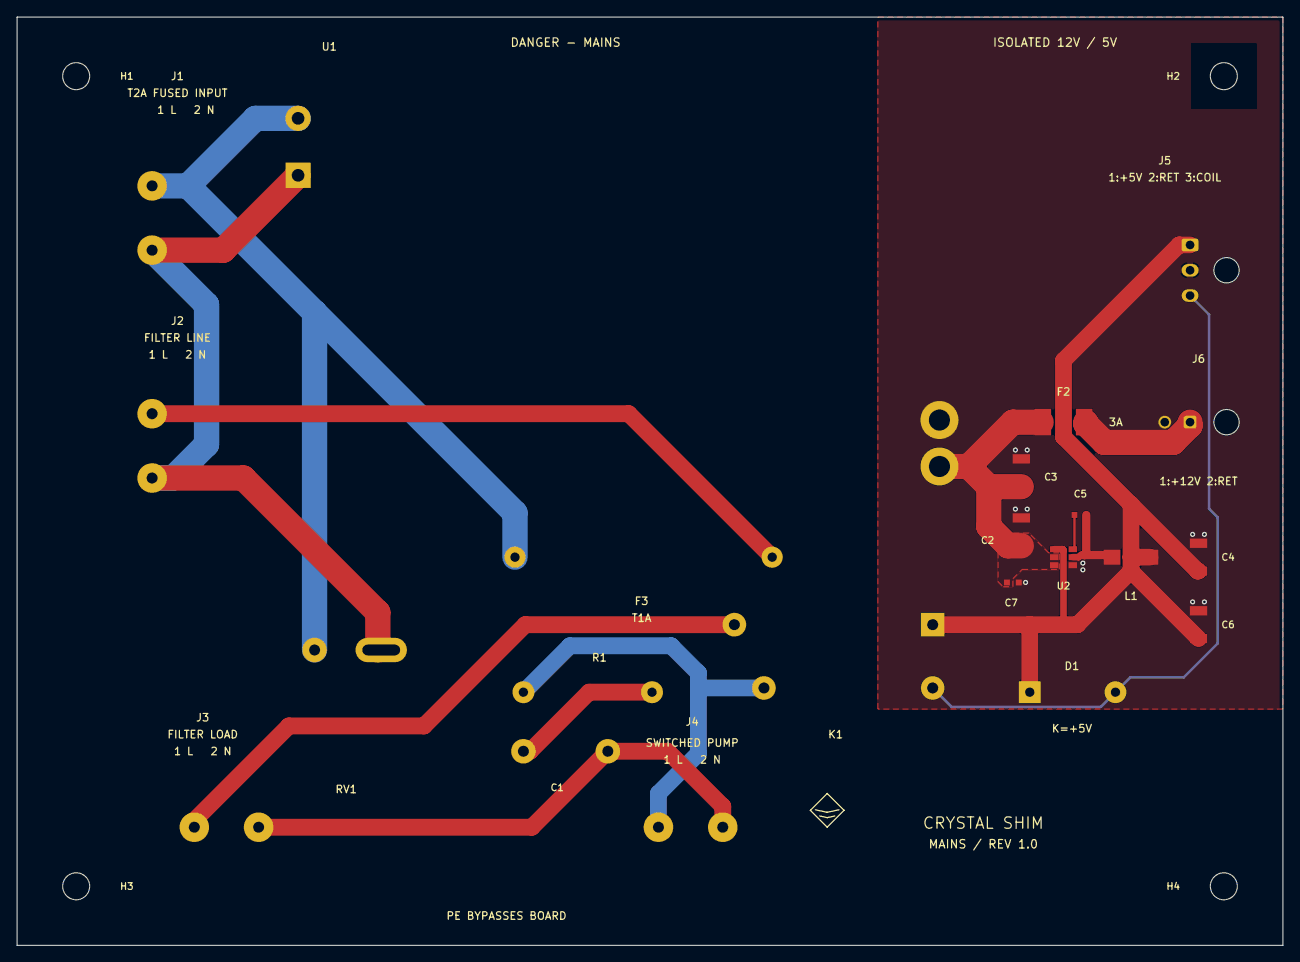
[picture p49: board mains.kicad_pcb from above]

Board: 2 copper layers, 150.0 x 110.0 mm, 26 parts (0 on the bottom side), 14 nets.

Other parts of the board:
H1: 3.2mm NPTH; Mains_H1
H2: 3.2mm NPTH; Mains_H2
H3: 3.2mm NPTH; Mains_H3
H4: 3.2mm NPTH; Mains_H4

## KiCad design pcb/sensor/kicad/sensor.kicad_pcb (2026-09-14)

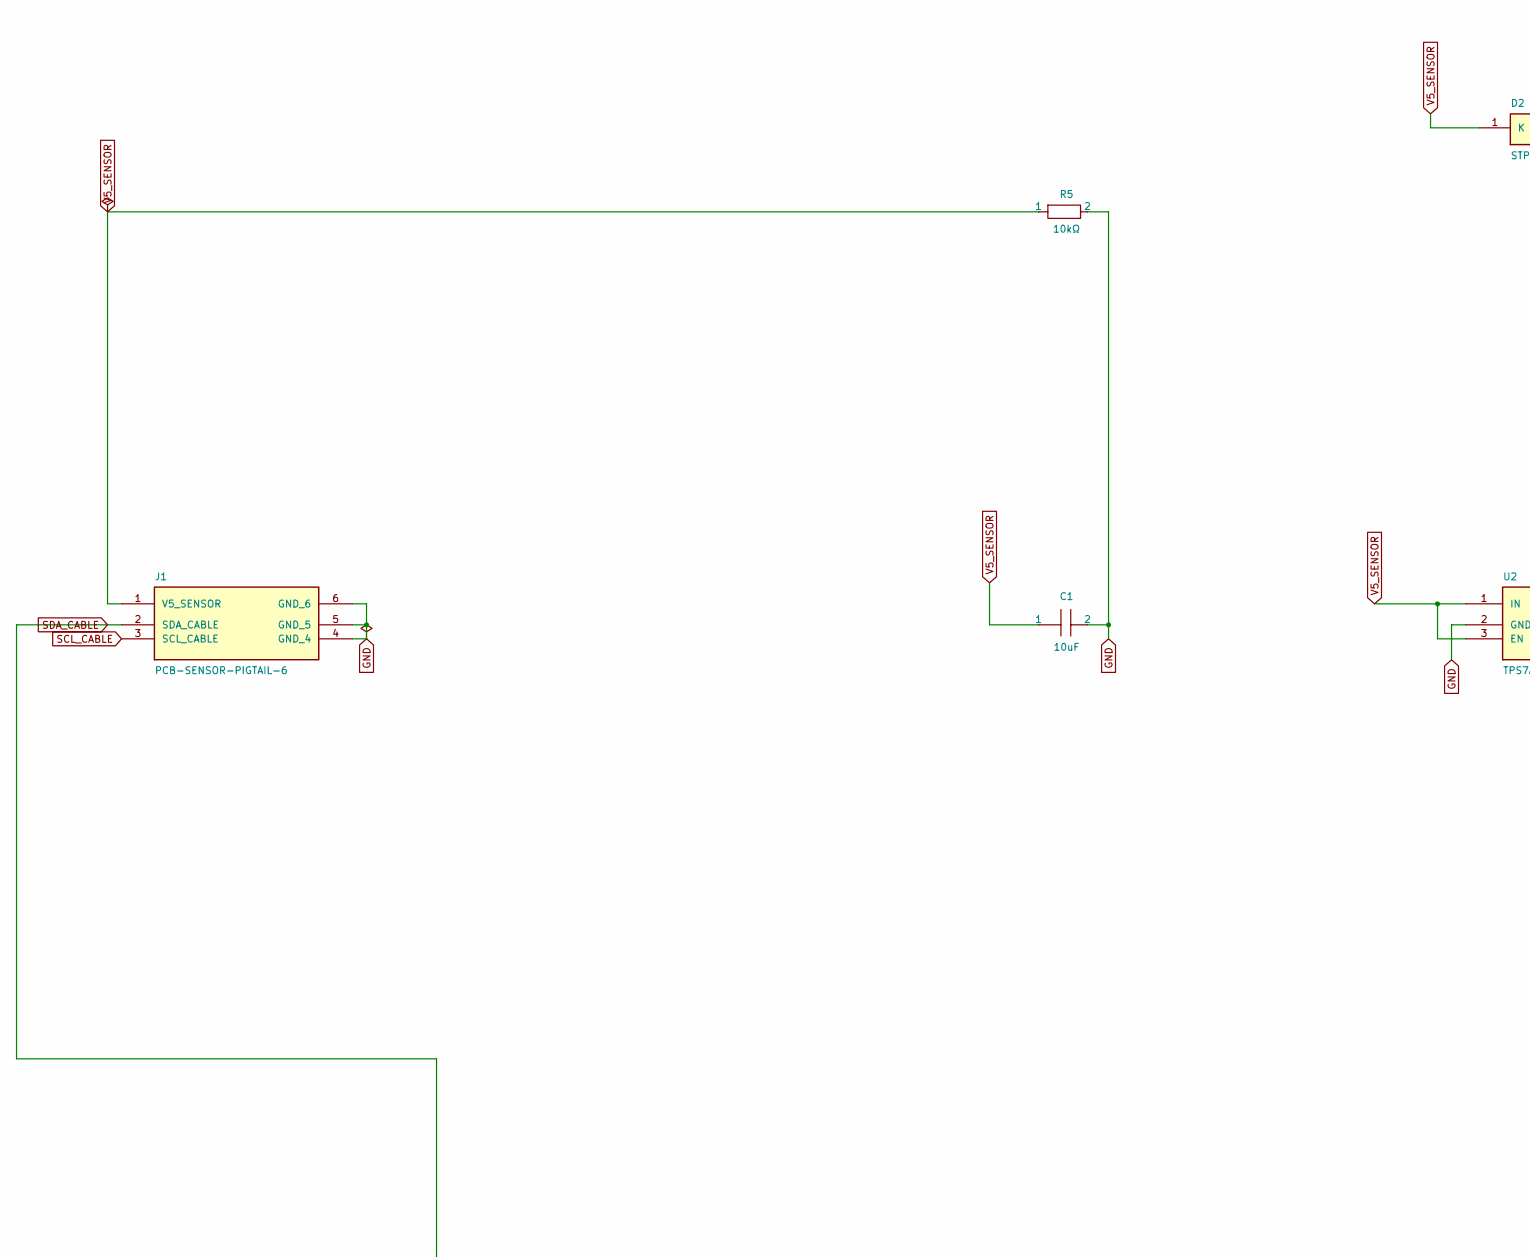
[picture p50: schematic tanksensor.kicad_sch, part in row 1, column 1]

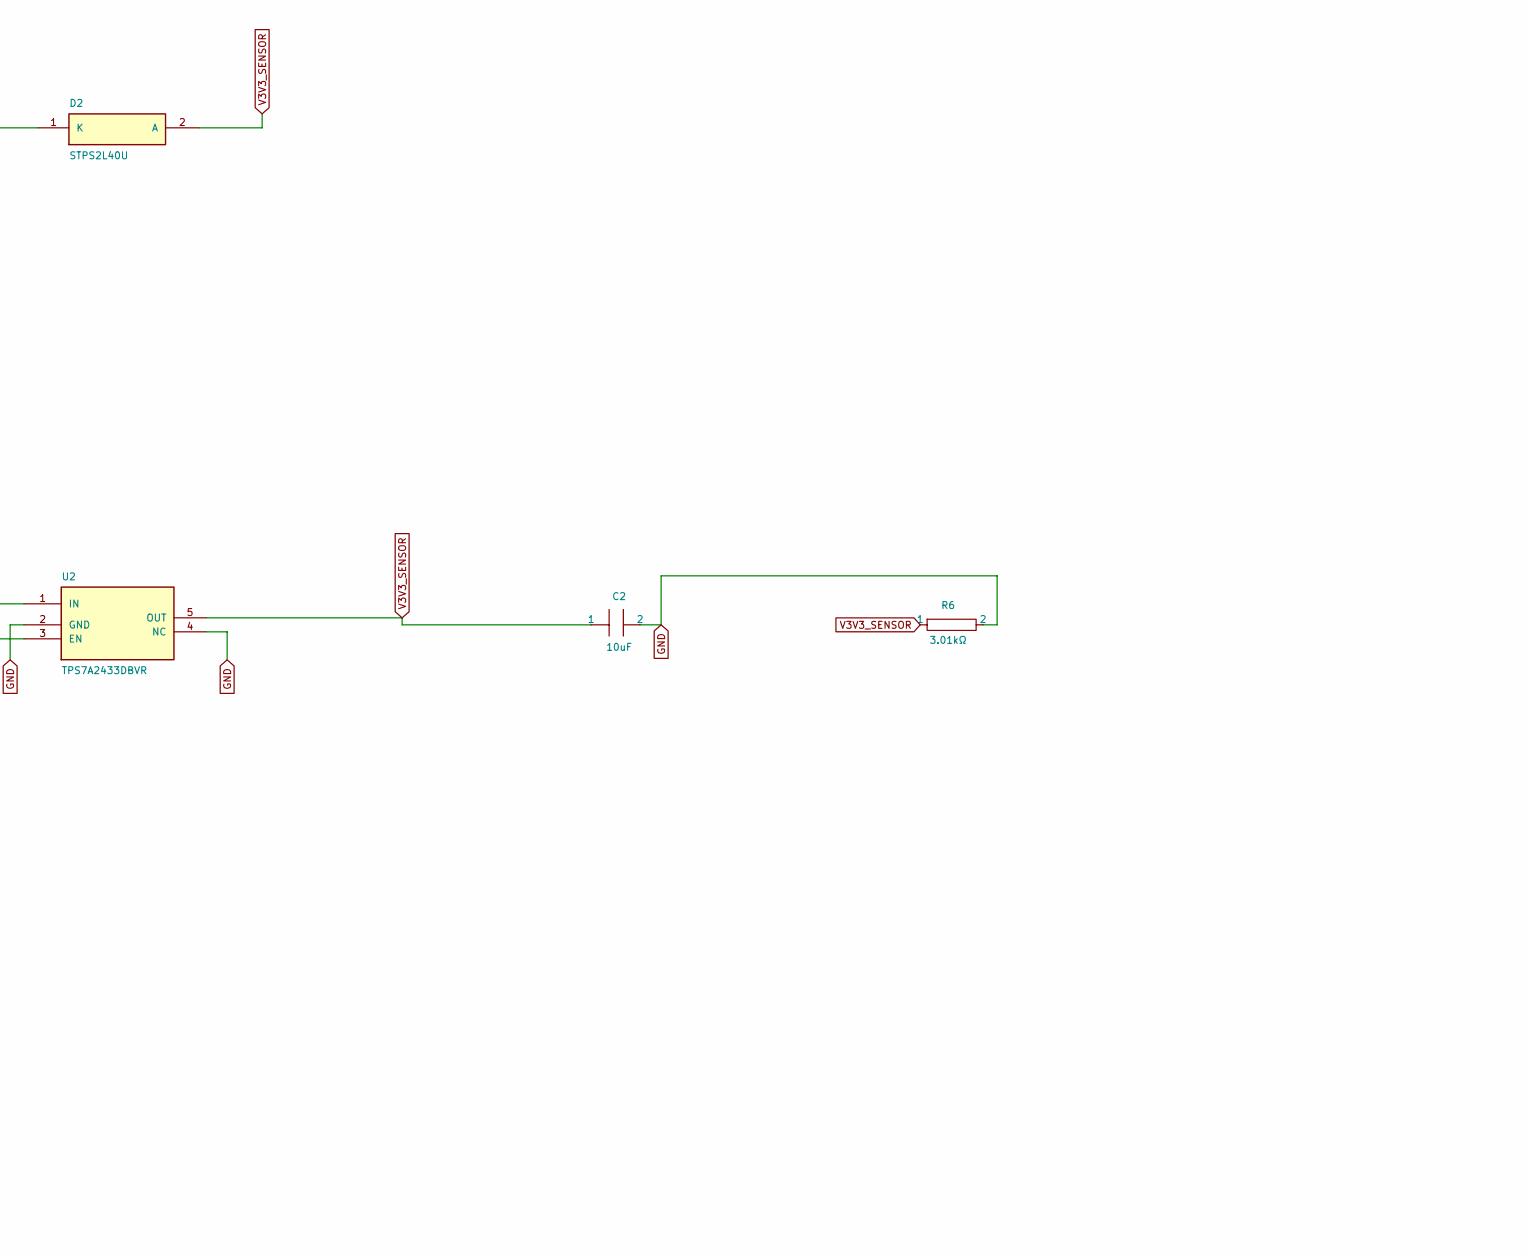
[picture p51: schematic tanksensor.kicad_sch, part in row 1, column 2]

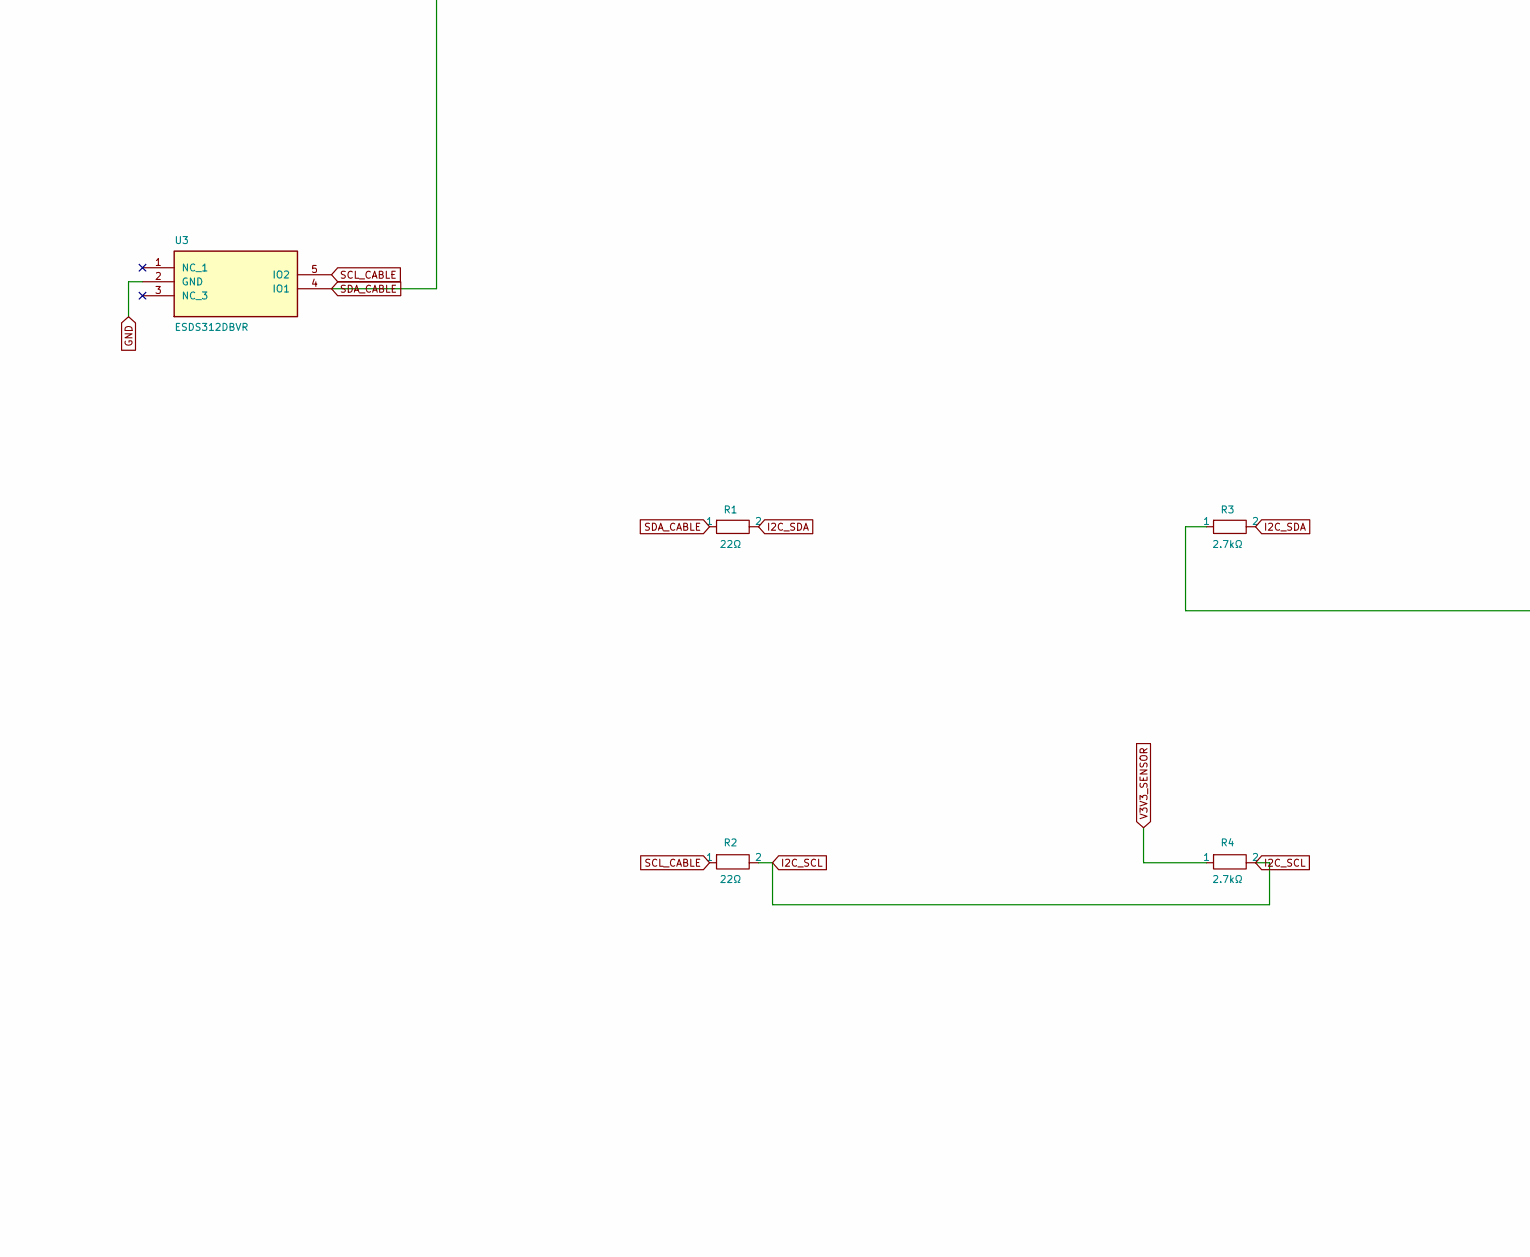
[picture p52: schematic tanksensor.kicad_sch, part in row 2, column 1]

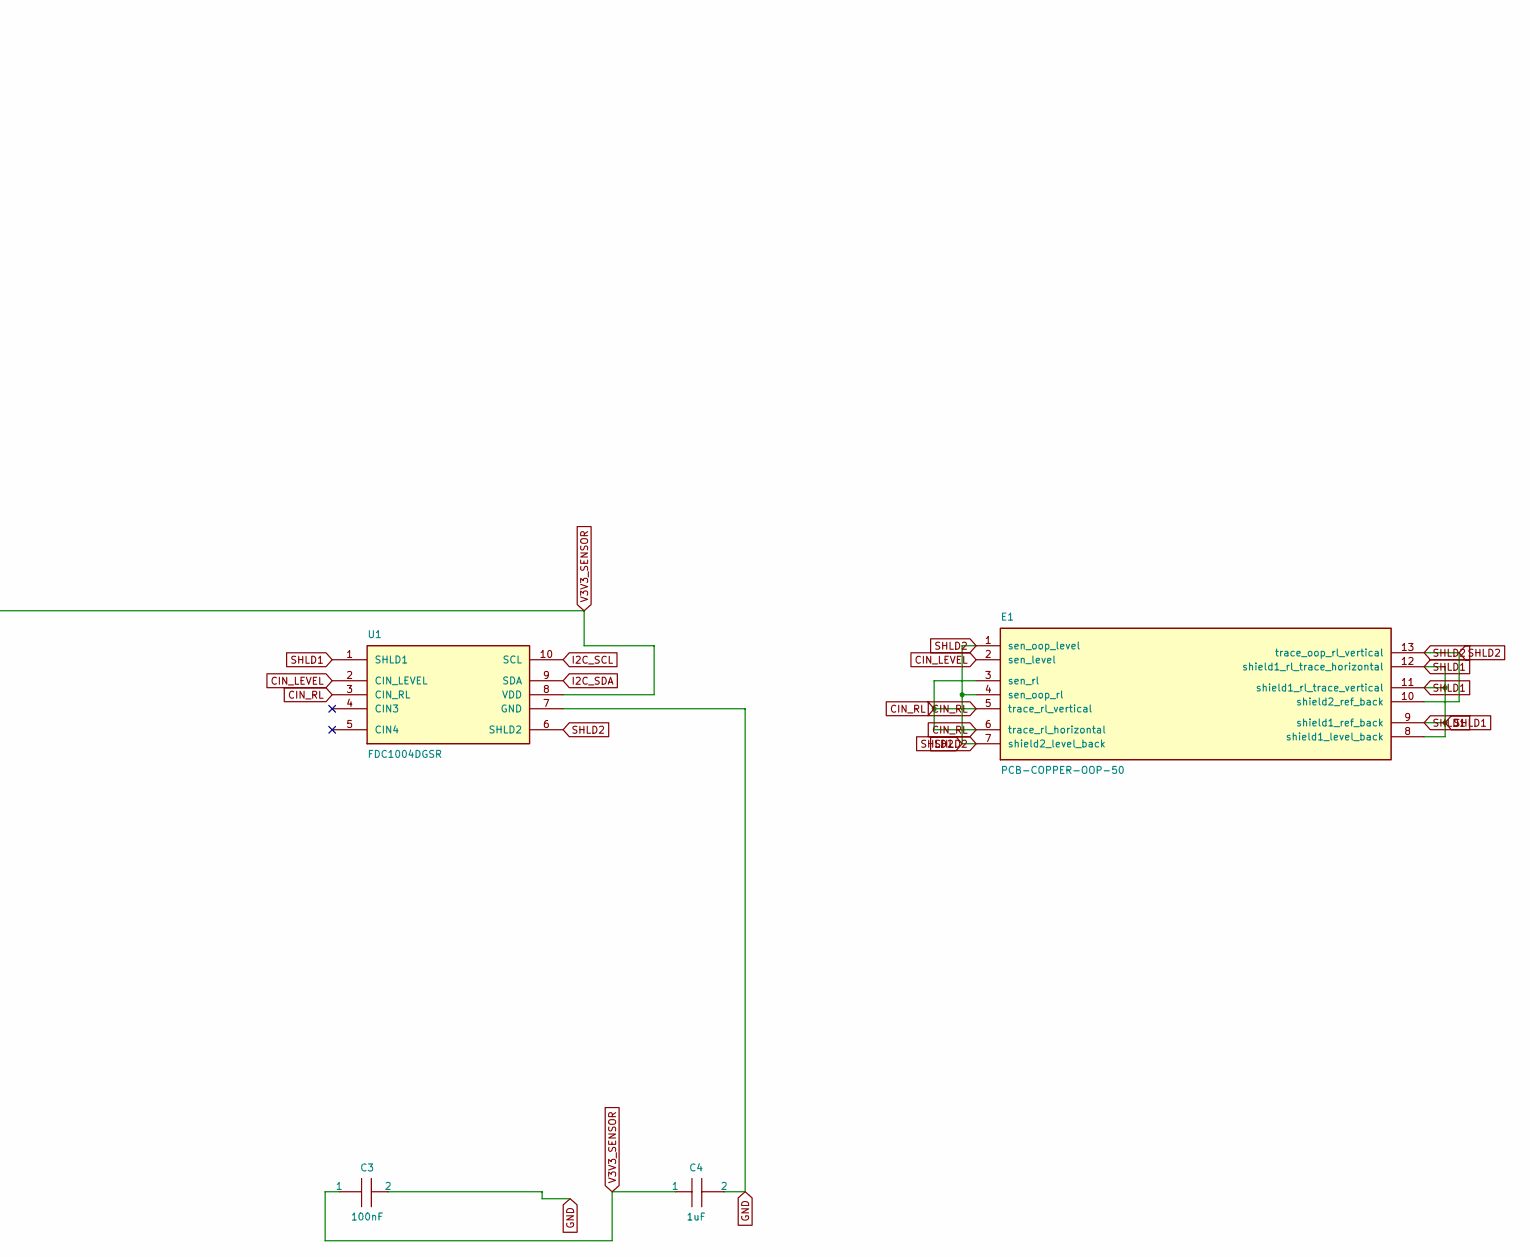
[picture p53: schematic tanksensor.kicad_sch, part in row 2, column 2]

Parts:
C1: 10uF; Sensor_C1; MPN C3216X7R1E106K160AB
C2: 10uF; Sensor_C2; MPN C3216X7R1E106K160AB
C3: 100nF; Sensor_C3; MPN C1608X7R1H104K080AA
C4: 1uF; Sensor_C4; MPN C2012X7R1E105K125AB
D2: STPS2L40U; Sensor_D2; MPN STPS2L40U
E1: PCB-COPPER-OOP-50; Sensor_E1; MPN PCB-COPPER-OOP-50
J1: PCB-SENSOR-PIGTAIL-6; Sensor_J1; MPN PCB-SENSOR-PIGTAIL-6
R1: 22Ω; Sensor_R1; MPN ERJ3EKF22R0V
R2: 22Ω; Sensor_R2; MPN ERJ3EKF22R0V
R3: 2.7kΩ; Sensor_R3; MPN ERJ3EKF2701V
R4: 2.7kΩ; Sensor_R4; MPN ERJ3EKF2701V
R5: 10kΩ; Sensor_R5; MPN ERJ3EKF1002V
R6: 3.01kΩ; Sensor_R6; MPN ERJ3EKF3011V
U1: FDC1004DGSR; Sensor_U1; MPN FDC1004DGSR
U2: TPS7A2433DBVR; Sensor_U2; MPN TPS7A2433DBVR
U3: ESDS312DBVR; Sensor_U3; MPN ESDS312DBVR

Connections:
CIN_LEVEL: E1.2 (sen_level), U1.2 (CIN_LEVEL)
CIN_RL: E1.3 (sen_rl), E1.5 (trace_rl_vertical), E1.6 (trace_rl_horizontal), U1.3 (CIN_RL)
GND: C1.2, C2.2, C3.2, C4.2, J1.4 (GND_4), J1.5 (GND_5), J1.6 (GND_6), R5.2, R6.2, U1.7 (GND), U2.2 (GND), U2.4 (NC), U3.2 (GND)
I2C_SCL: R2.2, R4.2, U1.10 (SCL)
I2C_SDA: R1.2, R3.2, U1.9 (SDA)
SCL_CABLE: J1.3 (SCL_CABLE), R2.1, U3.5 (IO2)
SDA_CABLE: J1.2 (SDA_CABLE), R1.1, U3.4 (IO1)
SHLD1: E1.8 (shield1_level_back), E1.9 (shield1_ref_back), E1.11 (shield1_rl_trace_vertical), E1.12 (shield1_rl_trace_horizontal), U1.1 (SHLD1)
SHLD2: E1.1 (sen_oop_level), E1.4 (sen_oop_rl), E1.7 (shield2_level_back), E1.10 (shield2_ref_back), E1.13 (trace_oop_rl_vertical), U1.6 (SHLD2)
V3V3_SENSOR: C2.1, C3.1, C4.1, D2.2 (A), R3.1, R4.1, R6.1, U1.8 (VDD), U2.5 (OUT)
V5_SENSOR: C1.1, D2.1 (K), J1.1 (V5_SENSOR), R5.1, U2.1 (IN), U2.3 (EN)

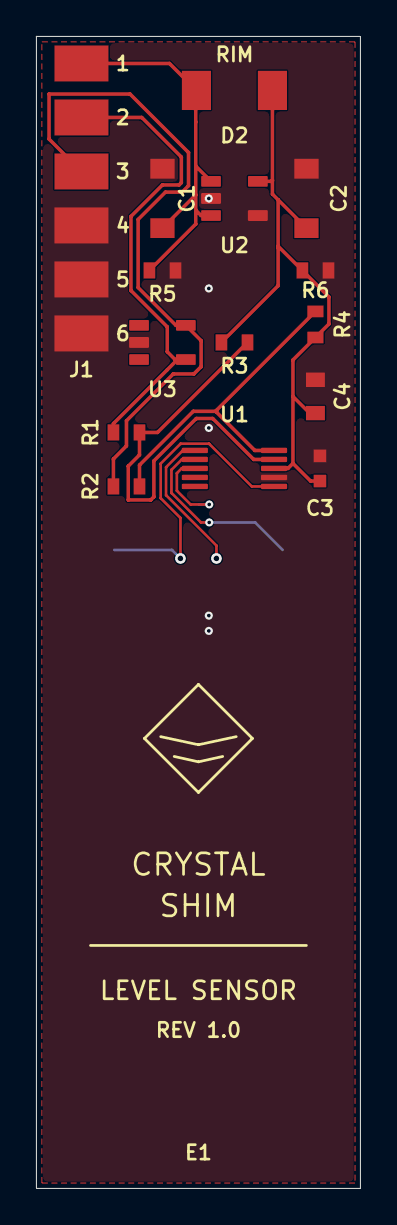
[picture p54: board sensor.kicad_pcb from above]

Board: 4 copper layers, 18.0 x 64.0 mm, 16 parts (0 on the bottom side), 11 nets.

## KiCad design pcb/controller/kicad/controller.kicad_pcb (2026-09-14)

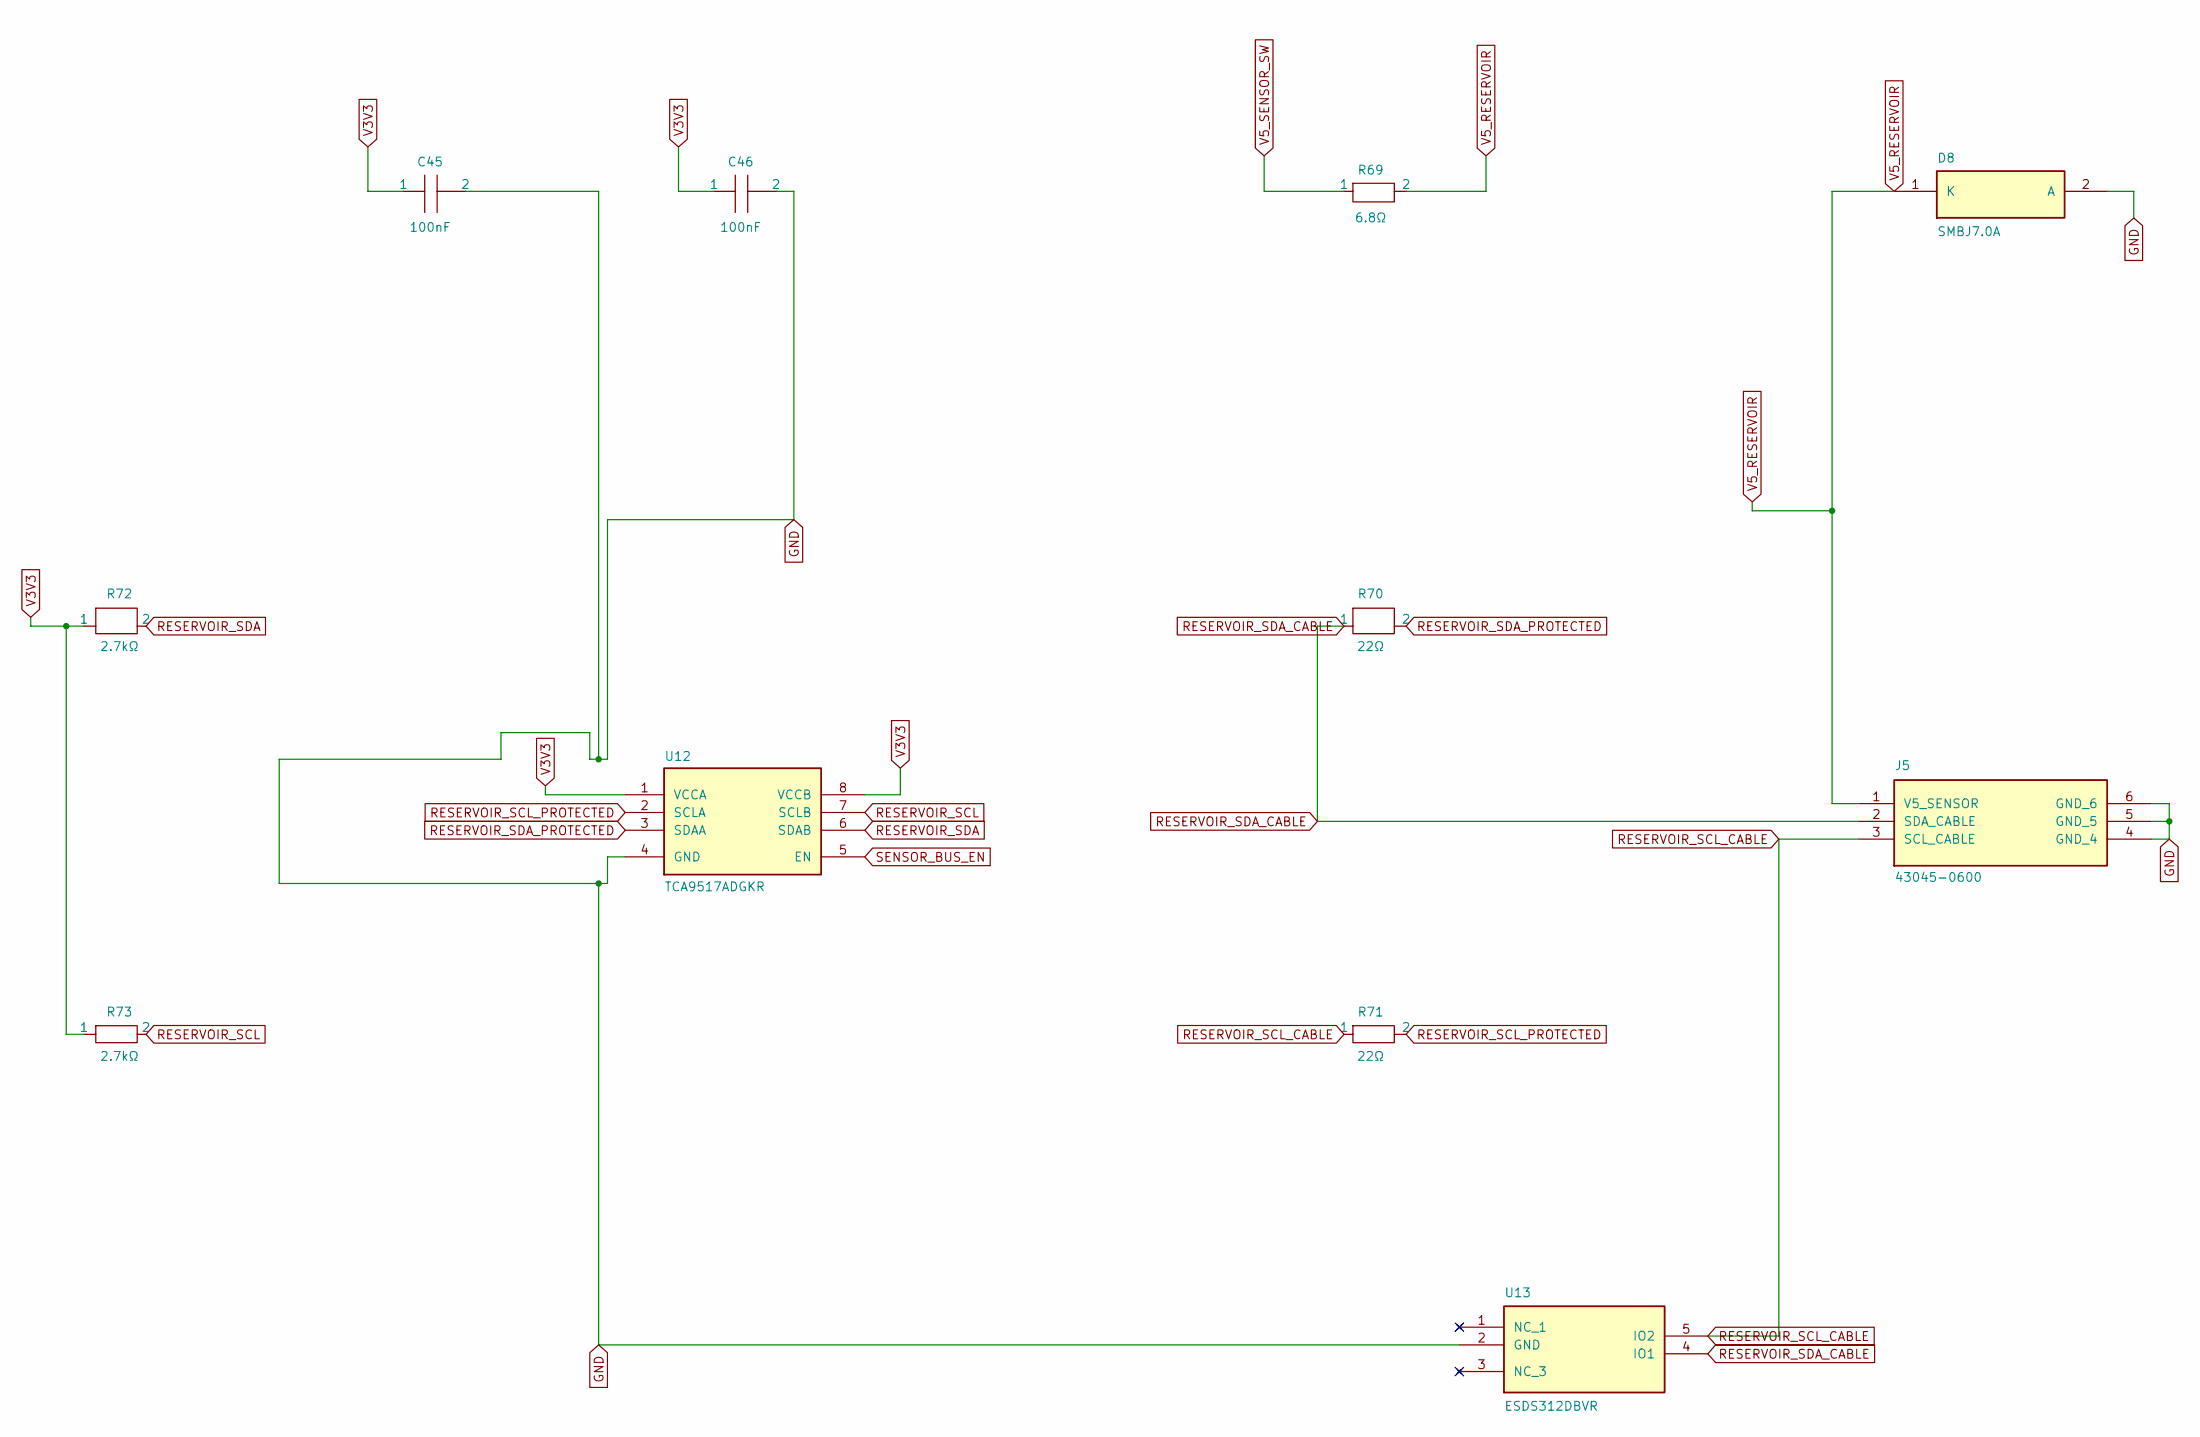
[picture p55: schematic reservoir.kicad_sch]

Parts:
C45: 100nF; Controller_C45; MPN C1608X7R1H104K080AA
C46: 100nF; Controller_C46; MPN C1608X7R1H104K080AA
D8: SMBJ7.0A; Controller_D8; MPN SMBJ7.0A
J5: 43045-0600; Controller_J5; MPN 43045-0600
R69: 6.8Ω; Controller_R69; MPN CRCW25126R80FKEGHP
R70: 22Ω; Controller_R70; MPN ERJ3EKF22R0V
R71: 22Ω; Controller_R71; MPN ERJ3EKF22R0V
R72: 2.7kΩ; Controller_R72; MPN ERJ3EKF2701V
R73: 2.7kΩ; Controller_R73; MPN ERJ3EKF2701V
U12: TCA9517ADGKR; Controller_U12; MPN TCA9517ADGKR
U13: ESDS312DBVR; Controller_U13; MPN ESDS312DBVR

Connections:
GND: C45.2, C46.2, D8.2 (A), J5.4 (GND_4), J5.5 (GND_5), J5.6 (GND_6), U12.4 (GND), U13.2 (GND); also elsewhere on the board
RESERVOIR_SCL: R73.2, U12.7 (SCLB); also elsewhere on the board
RESERVOIR_SCL_CABLE: J5.3 (SCL_CABLE), R71.1, U13.5 (IO2)
RESERVOIR_SCL_PROTECTED: R71.2, U12.2 (SCLA)
RESERVOIR_SDA: R72.2, U12.6 (SDAB); also elsewhere on the board
RESERVOIR_SDA_CABLE: J5.2 (SDA_CABLE), R70.1, U13.4 (IO1)
RESERVOIR_SDA_PROTECTED: R70.2, U12.3 (SDAA)
SENSOR_BUS_EN: U12.5 (EN); also elsewhere on the board
V3V3: C45.1, C46.1, R72.1, R73.1, U12.1 (VCCA), U12.8 (VCCB); also elsewhere on the board
V5_RESERVOIR: D8.1 (K), J5.1 (V5_SENSOR), R69.2
V5_SENSOR_SW: R69.1; also elsewhere on the board


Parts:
C20: 1uF; Controller_C20; MPN C2012X7R1E105K125AB
C21: 100nF; Controller_C21; MPN C1608X7R1H104K080AA
J2: S2B-XH-A; Controller_J2; MPN S2B-XH-A

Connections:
GND: C20.2, C21.2, J2.2 (RETURN); also elsewhere on the board
V5_SERVICE: C20.1, C21.1, J2.1 (POSITIVE); also elsewhere on the board



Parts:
C40: 100nF; Controller_C40; MPN C1608X7R1H104K080AA
C41: 100nF; Controller_C41; MPN C1608X7R1H104K080AA
C42: 100nF; Controller_C42; MPN C1608X7R1H104K080AA
C43: 1uF; Controller_C43; MPN C2012X7R1E105K125AB
C44: 10uF; Controller_C44; MPN C3216X7R1E106K160AB
D7: SMBJ7.0A; Controller_D7; MPN SMBJ7.0A
J3: 43045-0600; Controller_J3; MPN 43045-0600
R60: 2.7kΩ; Controller_R60; MPN ERJ3EKF2701V
R61: 2.7kΩ; Controller_R61; MPN ERJ3EKF2701V
R62: 22Ω; Controller_R62; MPN ERJ3EKF22R0V
R63: 22Ω; Controller_R63; MPN ERJ3EKF22R0V
R64: 10kΩ; Controller_R64; MPN ERJ3EKF1002V
R65: 10kΩ; Controller_R65; MPN ERJ3EKF1002V
R66: 10kΩ; Controller_R66; MPN ERJ3EKF1002V
R67: 10kΩ; Controller_R67; MPN ERJ3EKF1002V
R68: 6.8Ω; Controller_R68; MPN CRCW25126R80FKEGHP
U3: TCA9517ADGKR; Controller_U3; MPN TCA9517ADGKR
U5: TPS2553DBVR; Controller_U5; MPN TPS2553DBVR
U11: ESDS312DBVR; Controller_U11; MPN ESDS312DBVR

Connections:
GND: C40.2, C41.2, C42.2, C43.2, C44.2, D7.2 (A), J3.4 (GND_4), J3.5 (GND_5), J3.6 (GND_6), R64.2, R65.2, R67.2, U3.4 (GND), U5.2 (GND), U11.2 (GND); also elsewhere on the board
SCL_BUFFER_A: R63.1, U3.2 (SCLA)
SCL_CABLE: J3.3 (SCL_CABLE), R63.2, U11.5 (IO2)
SDA_BUFFER_A: R62.1, U3.3 (SDAA)
SDA_CABLE: J3.2 (SDA_CABLE), R62.2, U11.4 (IO1)
SENSOR_BUS_EN: R64.1, U3.5 (EN); also elsewhere on the board
SENSOR_POWER_EN: R65.1, U5.3 (EN); also elsewhere on the board
SENSOR_POWER_FAULT_N: R66.2, U5.4 (FAULT_N); also elsewhere on the board
SENSOR_SCL: R61.2, U3.7 (SCLB); also elsewhere on the board
SENSOR_SDA: R60.2, U3.6 (SDAB); also elsewhere on the board
V3V3: C40.1, C41.1, R60.1, R61.1, R66.1, U3.1 (VCCA), U3.8 (VCCB); also elsewhere on the board
V5_LOGIC: C42.1, U5.1 (IN), U5.5 (ILIM); also elsewhere on the board
V5_SENSOR: D7.1 (K), J3.1 (V5_SENSOR), R68.2
V5_SENSOR_SW: C43.1, C44.1, R67.1, R68.1, U5.6 (OUT); also elsewhere on the board

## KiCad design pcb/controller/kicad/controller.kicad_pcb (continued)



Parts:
C30: 100nF; Controller_C30; MPN C1608X7R1H104K080AA
C31: 100nF; Controller_C31; MPN C1608X7R1H104K080AA
J4: USB4105-GF-A; Controller_J4; MPN USB4105-GF-A
R40: 5.1kΩ; Controller_R40; MPN ERJ3EKF5101V
R41: 5.1kΩ; Controller_R41; MPN ERJ3EKF5101V
R42: 1kΩ; Controller_R42; MPN ERJ3EKF1001V
R43: 100kΩ; Controller_R43; MPN ERJ3EKF1003V
R44: 22Ω; Controller_R44; MPN ERJ3EKF22R0V
R45: 22Ω; Controller_R45; MPN ERJ3EKF22R0V
R46: 10kΩ; Controller_R46; MPN ERJ3EKF1002V
U7: SN74LVC1G14DBVR; Controller_U7; MPN SN74LVC1G14DBVR
U8: FSUSB42MUX; Controller_U8; MPN FSUSB42MUX
U9: USBLC6-2SC6; Controller_U9; MPN USBLC6-2SC6

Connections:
GND: C30.2, C31.2, J4.A1, J4.A12, J4.B1, J4.B12, J4.SH, R40.2, R41.2, R43.2, U7.3 (GND), U8.2 (SEL), U8.5 (GND), U9.2 (GND); also elsewhere on the board
USB_CC1: J4.A5, R40.1
USB_CC2: J4.B5, R41.1
USB_D_N: R44.2; also elsewhere on the board
USB_D_P: R45.2; also elsewhere on the board
USB_D_PORT_N: J4.A7, J4.B7, U8.4 (D_N), U9.3 (IO2_3), U9.4 (IO2_4)
USB_D_PORT_P: J4.A6, J4.B6, U8.3 (D_P), U9.1 (IO1_1), U9.6 (IO1_6)
USB_D_SWITCH_N: R44.1, U8.6 (HSD1_N)
USB_D_SWITCH_P: R45.1, U8.7 (HSD1_P)
USB_SWITCH_OE_N: R46.2, U7.4 (Y), U8.10 (OE_N)
USB_VBUS: J4.A4, J4.A9, J4.B4, J4.B9, R42.1, U9.5 (VBUS)
USB_VBUS_SENSE: R42.2, R43.1, U7.2 (A)
V3V3: C30.1, C31.1, R46.1, U7.5 (VCC), U8.1 (VCC); also elsewhere on the board





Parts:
C47: 22uF; Controller_C47; MPN GRM32ER71E226ME15L
D9: STPS2L40U; Controller_D9; MPN STPS2L40U
D10: STPS2L40U; Controller_D10; MPN STPS2L40U
D11: STPS2L40U; Controller_D11; MPN STPS2L40U
J6: 43045-0200; Controller_J6; MPN 43045-0200
J7: 43045-0200; Controller_J7; MPN 43045-0200
J8: 43045-0200; Controller_J8; MPN 43045-0200
J9: 43045-0200; Controller_J9; MPN 43045-0200
Q2: AO3400A; Controller_Q2; MPN AO3400A
Q3: AO3400A; Controller_Q3; MPN AO3400A
Q4: AO3400A; Controller_Q4; MPN AO3400A
R80: 100Ω; Controller_R80; MPN ERJ3EKF1000V
R81: 10kΩ; Controller_R81; MPN ERJ3EKF1002V
R82: 100Ω; Controller_R82; MPN ERJ3EKF1000V
R83: 10kΩ; Controller_R83; MPN ERJ3EKF1002V
R84: 100Ω; Controller_R84; MPN ERJ3EKF1000V
R85: 10kΩ; Controller_R85; MPN ERJ3EKF1002V

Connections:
CHLORINE_DRAIN: D10.2 (A), J8.2 (RETURN), Q3.3 (D)
CHLORINE_GATE: Q3.1 (G), R82.2, R83.1
DECHLOR_DRAIN: D11.2 (A), J9.2 (RETURN), Q4.3 (D)
DECHLOR_GATE: Q4.1 (G), R84.2, R85.1
GND: C47.2, J6.2 (RETURN), Q2.2 (S), Q3.2 (S), Q4.2 (S), R81.2, R83.2, R85.2; also elsewhere on the board
PUMP_CHLORINE: R82.1; also elsewhere on the board
PUMP_DECHLOR: R84.1; also elsewhere on the board
PUMP_TRANSFER: R80.1; also elsewhere on the board
TRANSFER_DRAIN: D9.2 (A), J7.2 (RETURN), Q2.3 (D)
TRANSFER_GATE: Q2.1 (G), R80.2, R81.1
V12_PUMP: C47.1, D9.1 (K), D10.1 (K), D11.1 (K), J6.1 (POSITIVE), J7.1 (POSITIVE), J8.1 (POSITIVE), J9.1 (POSITIVE)


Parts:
C11: 100nF; Controller_C11; MPN C1608X7R1H104K080AA
C12: 100nF; Controller_C12; MPN C1608X7R1H104K080AA
J1: 43650-0300; Controller_J1; MPN 43650-0300
Q1: AO3400A; Controller_Q1; MPN AO3400A
R2: 10kΩ; Controller_R2; MPN ERJ3EKF1002V
R11: 10kΩ; Controller_R11; MPN ERJ3EKF1002V
R12: 10kΩ; Controller_R12; MPN ERJ3EKF1002V
R14: 95.3kΩ; Controller_R14; MPN ERA3AEB9532V
R15: 10kΩ; Controller_R15; MPN ERA3AEB103V
R20: 100Ω; Controller_R20; MPN ERJ3EKF1000V
U4: TPS3808G01DBVR; Controller_U4; MPN TPS3808G01DBVR
U6: SN74LVC1G08DBVR; Controller_U6; MPN SN74LVC1G08DBVR

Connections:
CHIP_EN: U4.3 (MR_N); also elsewhere on the board
COIL_DRAIN: J1.3 (COIL_DRAIN), Q1.3 (D)
GND: C11.2, C12.2, J1.2 (GND), Q1.2 (S), R2.2, R11.2, R15.2, U4.2 (GND), U6.3 (GND); also elsewhere on the board
MOS_GATE: Q1.1 (G), R11.1, R20.2
PSU_GOOD: R12.2, U4.1 (RESET_N), U6.2 (B); also elsewhere on the board
PSU_SENSE: R14.2, R15.1, U4.5 (SENSE)
RELAY_GATED: R20.1, U6.4 (Y); also elsewhere on the board
RELAY_REQUEST: R2.1, U6.1 (A); also elsewhere on the board
V3V3: C11.1, C12.1, R12.1, U4.6 (VDD), U6.5 (VCC); also elsewhere on the board
V5_PSU: J1.1 (V5_PSU), R14.1; also elsewhere on the board


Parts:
TP1: TP1; Controller_TP1
TP2: TP2; Controller_TP2
TP3: TP3; Controller_TP3
TP4: TP4; Controller_TP4
TP5: TP5; Controller_TP5
TP6: TP6; Controller_TP6
TP7: TP7; Controller_TP7
TP8: TP8; Controller_TP8
TP9: TP9; Controller_TP9
TP10: TP10; Controller_TP10
TP11: TP11; Controller_TP11
TP12: TP12; Controller_TP12
TP13: TP13; Controller_TP13
TP14: TP14; Controller_TP14

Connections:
ACCESSORY_INPUT1: TP12.1; also elsewhere on the board
ACCESSORY_INPUT2: TP13.1; also elsewhere on the board
GND: TP1.1, TP11.1, TP14.1; also elsewhere on the board
PSU_GOOD: TP7.1; also elsewhere on the board
RELAY_GATED: TP8.1; also elsewhere on the board
SENSOR_SCL: TP6.1; also elsewhere on the board
SENSOR_SDA: TP5.1; also elsewhere on the board
UART0_RX: TP9.1; also elsewhere on the board
UART0_TX: TP10.1; also elsewhere on the board
V3V3: TP4.1; also elsewhere on the board
V5_LOGIC: TP3.1; also elsewhere on the board
V5_PSU: TP2.1; also elsewhere on the board


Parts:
C1: 22uF; Controller_C1; MPN GRM32ER71E226ME15L
C2: 22uF; Controller_C2; MPN GRM32ER71E226ME15L
C3: 22uF; Controller_C3; MPN GRM32ER71E226ME15L
C4: 22uF; Controller_C4; MPN GRM32ER71E226ME15L
C7: 100nF; Controller_C7; MPN C1608X7R1H104K080AA
C8: 100nF; Controller_C8; MPN C1608X7R1H104K080AA
D1: STPS2L40U; Controller_D1; MPN STPS2L40U
D2: STPS2L40U; Controller_D2; MPN STPS2L40U
L1: 4.7µH; Controller_L1; MPN SRP5030TA-4R7M
U2: AP63203WU-7; Controller_U2; MPN AP63203WU-7

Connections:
BUCK_BST: C8.1, U2.6 (BST)
BUCK_SW: C8.2, L1.1, U2.5 (SW)
GND: C1.2, C2.2, C3.2, C4.2, C7.2, U2.4 (GND); also elsewhere on the board
V3V3: C3.1, C4.1, L1.2, U2.1 (FB); also elsewhere on the board
V5_LOGIC: C1.1, C2.1, C7.1, D1.1 (K), D2.1 (K), U2.2 (EN), U2.3 (VIN); also elsewhere on the board
V5_PSU: D1.2 (A); also elsewhere on the board
V5_SERVICE: D2.2 (A); also elsewhere on the board

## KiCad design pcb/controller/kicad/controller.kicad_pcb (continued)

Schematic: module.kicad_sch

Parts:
C5: 22uF; Controller_C5; MPN GRM32ER71E226ME15L
C6: 100nF; Controller_C6; MPN C1608X7R1H104K080AA
C9: 1uF; Controller_C9; MPN C2012X7R1E105K125AB
D4: WP710A10LGD; Controller_D4; MPN WP710A10LGD
R50: 10kΩ; Controller_R50; MPN ERJ3EKF1002V
R51: 10kΩ; Controller_R51; MPN ERJ3EKF1002V
R52: 10kΩ; Controller_R52; MPN ERJ3EKF1002V
R53: 10kΩ; Controller_R53; MPN ERJ3EKF1002V
R54: 680Ω; Controller_R54; MPN ERJ3EKF6800V
R55: 330Ω; Controller_R55; MPN ERJ3EKF3300V
SW1: B3F-1002-G; Controller_SW1; MPN B3F-1002-G
SW2: B3F-1002-G; Controller_SW2; MPN B3F-1002-G
SW3: B3F-1002-G; Controller_SW3; MPN B3F-1002-G
U1: ESP32-C6-WROOM-1-N8; Controller_U1; MPN ESP32-C6-WROOM-1-N8

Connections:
ACCESSORY_INPUT1: U1.4 (IO4); also elsewhere on the board
ACCESSORY_INPUT2: U1.5 (IO5); also elsewhere on the board
BOOT_N: R51.2, SW2.1 (CONTACT_A), U1.15 (IO9)
BOOT_STRAP8: R52.2, U1.10 (IO8)
CHIP_EN: C9.1, R53.2, R55.1, U1.3 (EN); also elsewhere on the board
GND: C5.2, C6.2, C9.2, D4.1 (K), SW1.2 (CONTACT_B), SW2.2 (CONTACT_B), SW3.2 (CONTACT_B), U1.1 (GND_1), U1.28 (GND_28), U1.29 (GND_EP); also elsewhere on the board
LED_ANODE: D4.2 (A), R54.2
MAINTENANCE_N: R50.2, SW1.1 (CONTACT_A), U1.12 (IO11)
PSU_GOOD: U1.19 (IO21); also elsewhere on the board
PUMP_CHLORINE: U1.27 (IO2); also elsewhere on the board
PUMP_DECHLOR: U1.26 (IO3); also elsewhere on the board
PUMP_TRANSFER: U1.9 (IO1); also elsewhere on the board
RELAY_REQUEST: U1.11 (IO10); also elsewhere on the board
RESERVOIR_SCL: U1.7 (IO7); also elsewhere on the board
RESERVOIR_SDA: U1.6 (IO6); also elsewhere on the board
RESET_CONTACT: R55.2, SW3.1 (CONTACT_A)
SENSOR_BUS_EN: U1.8 (IO0); also elsewhere on the board
SENSOR_POWER_EN: U1.20 (IO22); also elsewhere on the board
SENSOR_POWER_FAULT_N: U1.21 (IO23); also elsewhere on the board
SENSOR_SCL: U1.17 (IO19); also elsewhere on the board
SENSOR_SDA: U1.16 (IO18); also elsewhere on the board
STATUS_LED: R54.1, U1.18 (IO20)
UART0_RX: U1.24 (RXD0_IO17); also elsewhere on the board
UART0_TX: U1.25 (TXD0_IO16); also elsewhere on the board
USB_D_N: U1.13 (IO12); also elsewhere on the board
USB_D_P: U1.14 (IO13); also elsewhere on the board
V3V3: C5.1, C6.1, R50.1, R51.1, R52.1, R53.1, U1.2 (V3V3); also elsewhere on the board


Board: 4 copper layers, 150.0 x 110.0 mm, 117 parts (0 on the bottom side), 63 nets.

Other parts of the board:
H1: 3.2mm NPTH; Controller_H1
H2: 3.2mm NPTH; Controller_H2
H3: 3.2mm NPTH; Controller_H3
H4: 3.2mm NPTH; Controller_H4

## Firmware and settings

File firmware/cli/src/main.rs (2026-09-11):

//! One stdin session runs one controller with simulated monotonic time. No device I/O.
use std::io::{self, BufRead};

use crystal_shim_core::{
    Command, Config, Fault, HardwarePermit, Inputs, Level, Millis, Reading, ScheduledWindow,
    Supervisor, SupervisorConfig, SwitchCommand, Timing, WindowId,
};

const USAGE: &str = "usage: crystal-shim-sim STOP RESTART MAX_SAMPLE_AGE_MS [LOW_MS RECOVERY_MS MIN_OFF_MS MAX_RUN_MS]\n\
    Thresholds are synthetic/calibrated thousandths (0..1000), STOP < RESTART.\n\
    stdin: <milliseconds> level <0..1000> | window <id> <absolute-end-ms> | no-window | on | off | tick | disconnected | uncalibrated | out-of-range | bus-fault | maintenance-on | maintenance-off | hardware-off | hardware-on\n\
    Each line advances one persistent simulation; tick reuses the last acquisition timestamp.\n\
    Supply events frequently enough to meet MAX_SAMPLE_AGE_MS. No GPIO or serial access.";

fn level(value: &str) -> Result<Level, String> {
    let number = value.parse().map_err(|_| "invalid integer level")?;
    Level::new(number).ok_or_else(|| "level must be 0..1000; use out-of-range for a fault".into())
}

fn event(line: &str, previous: Inputs) -> Result<(Millis, Inputs), String> {
    let fields: Vec<_> = line.split_whitespace().collect();
    let [time, action, rest @ ..] = fields.as_slice() else {
        return Err("expected a timestamp and action".into());
    };
    let now = Millis(time.parse().map_err(|_| "invalid timestamp")?);
    let mut input = Inputs {
        switch: SwitchCommand::None,
        maintenance: Command::None,
        ..previous
    };
    match (*action, rest) {
        ("level", [value]) => {
            input.reading = Reading::Valid {
                level: level(value)?,
                observed_at: now,
            }
        }
        ("tick", []) => {}
        ("disconnected", []) => input.reading = Reading::Invalid(Fault::Disconnected),
        ("uncalibrated", []) => input.reading = Reading::Invalid(Fault::Uncalibrated),
        ("out-of-range", []) => input.reading = Reading::Invalid(Fault::OutOfRange),
        ("bus-fault", []) => input.reading = Reading::Invalid(Fault::Bus),
        ("maintenance-on", []) => input.maintenance = Command::EnterMaintenance,
        ("maintenance-off", []) => input.maintenance = Command::ExitMaintenance,
        ("on", []) => input.switch = SwitchCommand::On,
        ("off", []) => input.switch = SwitchCommand::Off,
        ("hardware-off", []) => input.hardware = HardwarePermit::ForcedOff,
        ("hardware-on", []) => input.hardware = HardwarePermit::Allowed,
        ("no-window", []) => input.window = None,
        ("window", [id, end]) => {
            input.window = Some(ScheduledWindow {
                id: WindowId(id.parse().map_err(|_| "invalid window ID")?),
                ends_at: Millis(end.parse().map_err(|_| "invalid window end")?),
            })
        }
        _ => return Err("unknown action or wrong argument count".into()),
    }
    Ok((now, input))
}

fn initial_inputs() -> Inputs {
    Inputs {
        reading: Reading::Invalid(Fault::Uncalibrated),
        window: None,
        switch: SwitchCommand::None,
        maintenance: Command::None,
        hardware: HardwarePermit::Allowed,
    }
}

fn run() -> Result<(), String> {
    let args: Vec<_> = std::env::args().skip(1).collect();
    if args.as_slice() == ["--help"] || args.as_slice() == ["-h"] {
        println!("{USAGE}");
        return Ok(());
    }
    let [stop, restart, max_age, timers @ ..] = args.as_slice() else {
        return Err(USAGE.into());
    };
    let max_age = max_age.parse().map_err(|_| "invalid maximum sample age")?;
    let (timing, max_run) = match timers {
        [] => (Timing::PROVISIONAL, SupervisorConfig::INITIAL_MAX_RUN_MS),
        [low, recovery, min_off, max_run] => (
            Timing {
                low_confirmation_ms: low.parse().map_err(|_| "invalid low confirmation")?,
                recovery_ms: recovery.parse().map_err(|_| "invalid recovery")?,
                minimum_off_ms: min_off.parse().map_err(|_| "invalid minimum off")?,
            },
            max_run.parse().map_err(|_| "invalid maximum run")?,
        ),
        _ => return Err(USAGE.into()),
    };
    let config = Config::new(level(stop)?, level(restart)?, max_age, timing)
        .map_err(|error| format!("invalid configuration: {error:?}"))?;
    let config = SupervisorConfig::new(config, max_run)
        .map_err(|error| format!("invalid configuration: {error:?}"))?;
    let mut controller = Supervisor::new(config, Millis(0));
    let mut input = initial_inputs();
    println!("milliseconds,state,relay_command,demand,deadline_ms,water_state,water_transition");
    println!("0,Boot,Off,Off,,None,");
    for (index, line) in io::stdin().lock().lines().enumerate() {
        let line = line.map_err(|error| error.to_string())?;
        let line = line.trim();
        if line.is_empty() || line.starts_with('#') {
            continue;
        }
        let (now, next_input) =
            event(line, input).map_err(|error| format!("line {}: {error}", index + 1))?;
        input = next_input;
        let status = controller.update(now, input);
        let deadline = status
            .deadline
            .map(|time| time.0.to_string())
            .unwrap_or_default();
        let transition = status
            .water_transition
            .map(|edge| format!("{:?}->{:?}", edge.from, edge.to))
            .unwrap_or_default();
        println!(
            "{},{:?},{:?},{:?},{},{:?},{}",
            now.0,
            status.control.state,
            status.control.relay,
            status.demand,
            deadline,
            status.water_state,
            transition
        );
    }
    Ok(())
}

fn main() -> std::process::ExitCode {
    match run() {
        Ok(()) => std::process::ExitCode::SUCCESS,
        Err(error) => {
            eprintln!("{error}");
            std::process::ExitCode::FAILURE
        }
    }
}

#[cfg(test)]
mod tests {
    use super::*;

    #[test]
    fn tick_preserves_acquisition_time_and_bad_input_is_rejected() {
        let (_, reading) = event("100 level 600", initial_inputs()).unwrap();
        let (now, retained) = event("900 tick", reading).unwrap();
        assert_eq!(now, Millis(900));
        assert_eq!(retained, reading);
        assert!(event("900 level 1001", reading).is_err());
        assert!(event("900 tick extra", reading).is_err());
        assert!(event("900 unknown", reading).is_err());
    }
}

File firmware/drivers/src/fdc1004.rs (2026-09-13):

//! FDC1004 out-of-phase acquisition, SNOSCY5C sections 6.5.3 and 6.6.
//!
//! Each frame consists of two single conversions: CIN1-CIN4 and CIN2-CIN4.
//! CIN3 and CIN4 are physically open. This selects opposite-phase SHLD2 without
//! CAPDAC. Repeated mode is deliberately disabled so results cannot be overwritten
//! between the required MSB and LSB reads.
//!
//! The HAL must bound each I2C transaction independently (5 ms integration limit).
//! Run this future in the acquisition task, never in the relay-control task.
//! Cancellation or any acquisition error requires initialization before reuse.

use embedded_hal_async::{delay::DelayNs, i2c::I2c};

const ADDRESS: u8 = 0x50;
const FDC_CONF: u8 = 0x0c;
const RESET: u16 = 0x8000;
const RATE_100: u16 = 0x0400;
const CONFIGS: [u16; 2] = [0x0c00, 0x2c00];
const CONVERSION_TIMEOUT_MS: u64 = 40;
const FRAME_TIMEOUT_MS: u64 = 100;
const RAW_LIMIT: i32 = 15 * (1 << 19);

#[derive(Clone, Copy, Debug, Eq, PartialEq)]
pub enum Error<E> {
    Bus(E),
    NotInitialized,
    WrongDevice { manufacturer: u16, device: u16 },
    ConfigurationChanged { register: u8, actual: u16 },
    Timeout,
    ClockWentBackwards,
    MalformedResult,
    OutsideConverterRange,
}

/// Integer capacitance in units of 2^-19 pF, before tank calibration.
#[derive(Clone, Copy, Debug, Eq, PartialEq)]
pub struct RawCapacitance(i32);

impl RawCapacitance {
    pub const fn counts(self) -> i32 {
        self.0
    }
}

/// One complete ordered set. `started_ms` is the conservative freshness timestamp:
/// the two electrodes are sampled sequentially, not simultaneously.
#[derive(Clone, Copy, Debug, Eq, PartialEq)]
pub struct Frame {
    pub level: RawCapacitance,
    pub wet_reference: RawCapacitance,
    pub started_ms: u64,
    pub completed_ms: u64,
}

pub struct Fdc1004<I> {
    bus: I,
    initialized: bool,
    last_time: Option<u64>,
}

impl<I: I2c> Fdc1004<I> {
    pub const fn new(bus: I) -> Self {
        Self {
            bus,
            initialized: false,
            last_time: None,
        }
    }

    /// Return peripheral ownership for HAL recovery. Construct and initialize a new
    /// driver afterward; recovery cannot leave a previous frame marked valid.
    pub fn into_inner(self) -> I {
        self.bus
    }

    /// Recover/reset the bus peripheral separately before calling this after a
    /// cancelled or failed I2C transaction. Reset also restores gain/offset defaults.
    pub async fn initialize<D: DelayNs>(
        &mut self,
        delay: &mut D,
        now: impl Fn() -> u64,
    ) -> Result<(), Error<I::Error>> {
        self.initialized = false;
        // Initialization is also the explicit recovery boundary after a clock fault.
        self.last_time = None;
        let started = self.time(&now)?;
        let manufacturer = self.read(0xfe).await?;
        let device = self.read(0xff).await?;
        if manufacturer != 0x5449 || device != 0x1004 {
            return Err(Error::WrongDevice {
                manufacturer,
                device,
            });
        }
        self.write(FDC_CONF, RESET).await?;
        for attempt in 0..40 {
            let status = self.read(FDC_CONF).await?;
            self.deadline(&now, started, CONVERSION_TIMEOUT_MS)?;
            if status & RESET == 0 {
                break;
            }
            if attempt == 39 {
                return Err(Error::Timeout);
            }
            delay.delay_ms(1).await;
        }
        for (index, config) in CONFIGS.into_iter().enumerate() {
            self.write(0x08 + index as u8, config).await?;
        }
        self.verify_configuration().await?;
        self.deadline(&now, started, FRAME_TIMEOUT_MS)?;
        self.initialized = true;
        Ok(())
    }

    /// Acquire a complete frame or return an error without publishing partial data.
    /// Even cancellation between awaits invalidates the driver until reinitialized.
    pub async fn acquire<D: DelayNs>(
        &mut self,
        delay: &mut D,
        now: impl Fn() -> u64,
    ) -> Result<Frame, Error<I::Error>> {
        if !self.initialized {
            return Err(Error::NotInitialized);
        }
        self.initialized = false;
        let started_ms = self.time(&now)?;
        self.verify_configuration().await?;
        let mut values = [RawCapacitance(0); 2];
        for (index, value) in values.iter_mut().enumerate() {
            // Section 6.5.3.2 permits only one MEAS bit for a single trigger.
            // REPEAT=0; the example 0x0540 in that section contradicts its own
            // bit definition. Table 6-5 is authoritative: use 0x0440 for MEAS2.
            self.write(FDC_CONF, RATE_100 | (0x80 >> index)).await?;
            let conversion_started = self.time(&now)?;
            for attempt in 0..40 {
                let status = self.read(FDC_CONF).await?;
                self.deadline(&now, conversion_started, CONVERSION_TIMEOUT_MS)?;
                self.deadline(&now, started_ms, FRAME_TIMEOUT_MS)?;
                if status & (RESET | 0x0100) != 0 {
                    return Err(Error::ConfigurationChanged {
                        register: FDC_CONF,
                        actual: status,
                    });
                }
                if status & (0x08 >> index) != 0 {
                    break;
                }
                if attempt == 39 {
                    return Err(Error::Timeout);
                }
                delay.delay_ms(1).await;
            }
            let register = 2 * index as u8;
            let msb = self.read(register).await?;
            let lsb = self.read(register + 1).await?;
            *value = decode(msb, lsb)?;
        }
        // A brownout partway through the frame must not pass as two valid zeros.
        self.verify_configuration().await?;
        let completed_ms = self.deadline(&now, started_ms, FRAME_TIMEOUT_MS)?;
        self.initialized = true;
        Ok(Frame {
            level: values[0],
            wet_reference: values[1],
            started_ms,
            completed_ms,
        })
    }

    async fn verify_configuration(&mut self) -> Result<(), Error<I::Error>> {
        for (index, expected) in CONFIGS.into_iter().enumerate() {
            let register = 0x08 + index as u8;
            let actual = self.read(register).await?;
            if actual != expected {
                return Err(Error::ConfigurationChanged { register, actual });
            }
        }
        Ok(())
    }

    fn time(&mut self, now: &impl Fn() -> u64) -> Result<u64, Error<I::Error>> {
        let value = now();
        if self.last_time.is_some_and(|previous| value < previous) {
            return Err(Error::ClockWentBackwards);
        }
        self.last_time = Some(value);
        Ok(value)
    }
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

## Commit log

2026-09-11 Set up Crystal Shim hardware and firmware project
    [bom.csv, test-matrix.csv]
2026-09-11 Record remaining design inputs and sensor prototype priority
2026-09-11 Record freshwater mounting and local settings requirements
    [bom.csv, test-matrix.csv]
2026-09-11 Orient the project around one complete hardware build
    [test-matrix.csv]
2026-09-12 Add firmware foundations and sourced board design basis
    [bom.csv, test-matrix.csv]
2026-09-12 Integrate sensor calibration and fail-closed ESP runtime
    [test-matrix.csv]
2026-09-12 Restore validated settings with relay-off flash access
    [test-matrix.csv]
2026-09-12 Specify protected secondary power and sensor regulation
    [bom.csv, test-matrix.csv]
2026-09-12 Capture verified controller components and small parts
    [bom.csv, test-matrix.csv]
2026-09-12 Capture controller power sections and service supply
    [bom.csv, test-matrix.csv]
2026-09-12 Add runtime control and checked PCB component exports
    [test-matrix.csv]
2026-09-12 Use fixed-size chunks accepted by current stable Clippy
2026-09-12 Integrate controller sensing and real Matter connectivity
    [bom.csv, test-matrix.csv]
2026-09-12 Use fixed-size hex chunks with current Rust Clippy
2026-09-12 Add bounded trusted UTC and capture mains power circuits
    [bom.csv]
2026-09-12 Add signed time verification and advance PCB capture
    [bom.csv]
2026-09-12 Add local settings and harden timing, TLS and schematic handoff
    Link the bounded authenticated settings service and UI to the shared C6 network
    and storage owners. Confirm Off independently of configuration storage, discard
    older queued starts and clock changes, and preserve correlated durable replies.
    Add conservative UTC intervals, a borrowed rejection-only TLS certificate seam
    with provenance guards and real blocking/async failure tests, and an initial
    schematic grid/junction transform that survives native KiCad Save without losing
    connections. Record adversarial findings, fixes, current limits and the next USB
    layout step while retaining the original full-delivery goal.
    Validation: com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
    [main.rs]
2026-09-12 Expose response timing settings and clarify USB schematic
2026-09-12 Enforce strict schematic cleanup and fix module label layout
2026-09-12 Adopt controller KiCad board and verify signed-time agreement
    [controller.kicad_pcb, controller.kicad_sch, module.kicad_sch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]
2026-09-12 Integrate the complete mains circuit and MOV assembly contract
    [bom.csv]
2026-09-13 Prepare mains KiCad export and validate enclosure service fit
2026-09-13 Record mated J3 housing limits and unresolved metal datums
2026-09-13 Prepare verified mains schematic metadata and annotations
2026-09-13 Require shared power-board capacity for future refill pumps
2026-09-13 Prepare simplified shared-power boards for routing
    [bom.csv, controller.kicad_pcb, controller.kicad_sch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]
2026-09-13 Prepare filled planes and enforce KiCad routing guardrails
    [controller.kicad_pcb, mains.kicad_pcb, sensor.kicad_pcb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]
2026-09-13 Record slim adhesive-mounted sensor visual target
2026-09-13 Propose shared footprint for stacked power and controller boards
2026-09-13 Save accepted stacked-board visual reference and specification
2026-09-13 Prepare compact three-board designs for owner routing
    [bom.csv, controller.kicad_pcb, fit-screen.step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]
2026-09-13 Harden PCB changes with verified native transactions
2026-09-14 Simplify mains connectors and separate the 5 V service input
    [bom.csv, controller.kicad_pcb, mains.kicad_pcb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]
2026-09-14 Record sensor routing review and acceptance follow-up
2026-09-14 Adopt C3 placement and review sensor glass-side connections
2026-09-14 Accept completed sensor routing and preserve its checked baseline
    [sensor.kicad_pcb]
2026-09-14 Accept completed mains routing with bounded feedback branch
    [mains.kicad_pcb]
2026-09-14 Prepare all three boards for standard JLCPCB ordering
    [bom.csv, consolidated-purchase.csv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]
2026-09-14 Link the live PCB order guide and parts BOM
2026-09-14 Prepare verified DigiKey Canada parts cart
    [cart-lines.csv, digikey-bulk-add.csv, not-in-cart.csv]
2026-09-14 Record DigiKey order 101602605 and current stock
    [bom.csv, inventory.csv, ordered-items.csv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]
2026-09-14 Record available wiring consumables and support stock
    [bom.csv, inventory.csv]
2026-09-14 Record remaining assembly supplies as owner stock
    [bom.csv, inventory.csv]
2026-09-14 Record sensor cable order and MOV sourcing review
    [bom.csv, inventory.csv]
2026-09-14 Fit the bulk MOV and refresh mains fabrication outputs
    [bom.csv, inventory.csv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]
2026-09-14 Record six spacer blanks added to Mouser cart
2026-09-14 Record Mouser order 40452969 and close component procurement
    [bom.csv, inventory.csv]
2026-09-14 Add illustrated assembly bench guide for all three boards
2026-09-14 Record completed assembly booklet print job
2026-09-14 Wrap assembly booklet work and preserve delivery handoff
2026-09-14 Add printable stencil fixtures for all three PCBs
    [controller-shim-0.2mm.3mf, controller-shim-0.2mm.step, controller-shim-0.2mm.stl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]
2026-10-01 Reconcile received orders and pending Mouser release
    [bom.csv, inventory.csv, ordered-items.csv]
2026-10-06 Record Mouser receipt and PCBs in hand
    Mouser cancelled the six-spacer line on 2026-10-01 and shipped the 11
    electronics on 2026-10-02 (invoice 92822100). Michael reported the order
    received and the PCBs in hand on 2026-10-05 America/Vancouver.
    All 103 inventory allocations are now In stock by reconciling earlier
    records with this reported receipt; no new physical count is claimed.
    Spacer allocations return to owner-held stock. Board count, inspection,
    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
    [bom.csv, inventory.csv]
2026-10-12 Integrate esp-lan-ota OTA updates with gated flash and safe resets
    Pin esp-lan-ota 9b6df67 and move the app to an OTA layout: unchanged NVS
    (0x9000/0x6000), otadata and two equal 0x3F0000 slots on the 8 MiB WROOM.
    scripts/flash.sh is the only USB flash path; it writes the vendored,
    checksummed rollback bootloader, targets ota_0 and erases only otadata.
    The updater's flash client (OtaFlash) uses the relay-off permit per chunk
    and may program only otadata and the spare slot. Flash tickets now wake
    the control task so each chunk costs one iteration, not a 20 ms tick.
    Uploads start only while the output is idle; update and rollback resets
    wait briefly for storage and hold a permit so the relay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
